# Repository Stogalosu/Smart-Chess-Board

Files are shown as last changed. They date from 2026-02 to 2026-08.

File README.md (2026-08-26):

# Smart Chess Board

## What?
A smart chess board that connects to your phone and automatically makes the moves you and your opponent make on the screen. It can even play against you! It works by moving a magnet under the board, thus also moving the pieces which will have magnets in them.

## Why?
Because I had this idea in the back if my head for a long time and I thought this was the perfect time. Also, I wanted a challenge, something new.

## How do I use it?
Well, I haven't thought it through, but my idea is to also make an Android app that connects through Bluetooth with the board so you can visualise the moves there, as well as make new ones. I also hope to allow players to make their own moves on the board using the Hall sensors that are in the board.

## Firmware
There is no firmware... yet. I've just finished assembling the board and will start working on the firmware soon. 

## Disclosure
This project has already been submitted to Blueprint a few months ago. In the meantime, I've made some small additions and adjustments that I've recorded using Lapse. These include:
- Adding pin holes on the x-axis idlers for the pulleys and then increasing their tolerances.
- Modifying X-carriage to avoid interference of belts with other moving pieces.
- Adding snap fit to every chess piece.
- Adding fillets to board edges.
- Reworking screw holes on the sides of the board.
- Strengthening the bottom of the board.
- Adjusting eject mechanism angle.
- Adjusting position of holes for Raspberry Pi.
- Adding holes in the bottom of the board for belt tensioning screws.
- Adding spaces for pin solders on the back of the PCB.
- Widening nut spaces in all pieces.
- Fixing nut holes for the motor holes; the nut was too close to the motor.
- Fixing small problems before shipping.

## Assembly
Print all pieces. Make sure to follow the color scheme of a real chess board and keep track of which piece is which, as some of the screw holes won't align if their positions are wrong. Slide together the 4 pieces that make up the bottom of the board while inserting the y-axis rods, the x-axis idlers and the x-axis guiderail. Screw in the motor holders and the motors. Cut your belt into 2 pieces. Slide them into the x-axis carriage and fit the belts on the pulleys as described in the following image. Screw in the x-axis carriage. Attach the servomotor.



Solder the pieces onto the PCB and solder them together by connecting the pins. Connect the botton pieces of the play surface with the little pins. Fit the PCBs into it, then screw in each wall piece while keeping track of its position. Connect the motor cables and the Raspberry Pi.

At the end, cover the bottom with the play surface and screw in all the screws. Done!

## Images
Build:


3D Render:


PCB that has the Raspberry Pi on it:


The other PCB, which will be used 3 times to form a grid:


Wiring diagrams for the special PCB:



Wiring diagram for tileable PCB:


## BOM table
|Name |Price/unit|Amount|Shipping|Product Cost|Notes |Link |
|---|---|---|---|---|---|---|
|X-axis guiderail |$13,37 |1 |$0,00 |$13,37 |MGN9H, 350mm |https://www.aliexpress.com/item/1005002516956172.html |
|Y-axis Steel Rod |$2,21 |2 |$1,12 |$5,54 |6mm, 350mm |https://www.aliexpress.com/item/1005007648646117.html |
|Y-axis Linear Bearing |$1,26 |2 |$0,00 |$2,52 |LM6UU |https://www.optimusdigital.ro/ro/mecanica-rulmenti/3812-rulment-liniar-lm6uu.html |
|Stepper Motor |$3,88 |2 |$0,00 |$7,76 | |https://www.optimusdigital.ro/ro/motoare-motoare-pas-cu-pas/101-driver-uln2003-motor-pas-cu-pas-de-5-v-.html|
|Servomotor |$3,20 |1 |$0,00 |$3,20 | |https://www.optimusdigital.ro/ro/motoare-servomotoare/26-micro-servomotor-sg90.html |
|Neodymium Magnet 6x3mm |$2,26 |1 |$0,00 |$2,26 | |https://www.emag.ro/magnet-neodim-disc-6mm-x-3mm-00004824/pd/DZW0Y6BBM/ |
|Neodymium Magnet 10x3mm |$6,97 |2 |$6,48 |$20,42 |100pcs |https://www.aliexpress.com/item/1005010439392352.html |
|GT2 Belt |$2,31 |1 |$1,82 |$4,13 | |https://www.robofun.ro/3d-printer-cnc/curea-gt2-la-metru-liniar.html |
|M3x6 Headless Screws |$0,08 |10 |$0,00 |$0,77 | |https://www.optimusdigital.ro/ro/mecanica-suruburi-si-piulite/5785-m3x6-mm-urub-de-fixare-cu-cap-plat.html  |
|M3x6 Screws |$0,02 |100 |$6,00 |$8,00 |Minimum quantity|https://www.tme.eu/ro/details/m3x6_d912-a2/suruburi-cu-piulita/kraftberg/ |
|M3x10 Screws |$0,03 |100 |$0,00 |$3,20 |Minimum quantity|https://www.tme.eu/ro/details/b3x10_bn3/suruburi-cu-piulita/bossard/1003771/ |
|Steel Pins 2.5x10mm |$4,60 |1 |$0,00 |$4,60 |50pcs |https://www.aliexpress.com/item/1005003326358562.html |
|Steel Pins 4x30mm |$5,04 |1 |$0,00 |$5,04 |20pcs |https://www.aliexpress.com/item/1005003326358562.html |
|GT2 Timing Pulleys 5pcs |$5,53 |1 |$2,99 |$8,52 |20T W6 B5 |https://www.aliexpress.com/item/1005001933418605.html |
|GT2 Idler Timing Pulleys 12pcs|$9,28 |2 |$2,99 |$21,55 |20T W6 B4 |https://www.aliexpress.com/item/1005007557987612.html |
|Hall Sensors |$0,41 |65 |$0,00 |$26,65 | |https://www.tme.eu/ro/details/ss30at/senzori-hall/honeywell/ |
|I2C I/O expander |$1,66 |1 |$0,00 |$1,66 | |https://www.tme.eu/ro/en/details/tca9555pwr/interfaces-others-integrated-circuits/texas-instruments/ |
|I2C Driver |$1,69 |1 |$0,00 |$1,69 | |https://www.tme.eu/ro/en/details/tbd62083afwg/drivers-integrated-circuits/toshiba/ |
|Resistor network |$0,30 |1 |$0,00 |$0,30 | |https://www.tme.eu/ro/en/details/4609x-101-103lf/resistor-networks/bourns/ |
|Bus transciever |$0,80 |1 |$0,00 |$0,80 | |https://www.tme.eu/ro/en/details/sn74hct245dwr/latches/texas-instruments/ |
|Resistors |$0,03 |5 |$0,00 |$0,13 | |https://www.tme.eu/ro/details/rc1206fr-072k7/rezistente-smd/yageo/rc1206fr-072k7l/ |
|Inductors |$0,41 |4 |$0,00 |$1,64 | |https://www.tme.eu/ro/details/b82422h1103k000/inductoare/epcos-tdk/ |
|Polarized Capacitors |$0,70 |4 |$0,00 |$2,80 | |https://www.tme.eu/ro/details/tajc107k010r/condensatoare-cu-tantal-smd/kyocera-avx/tajc107k010rnj/ |
|Capacitors |$0,17 |3 |$0,00 |$0,51 | |https://www.tme.eu/ro/details/cl31b104kbcnnnd/condensatoare-mlcc-smd/samsung/ |
|40 pin Connector Female |$0,46 |1 |$0,00 |$0,46 | |https://www.tme.eu/ro/details/zl262-40dg/pini-cu-benzi-si-soclu/connfly/ds1023-2-20s21/ |
|40 pin Connector Male |$4,51 |1 |$0,00 |$4,51 | |https://www.tme.eu/ro/details/zl2038-40/pini-cu-benzi-si-soclu/ninigi/ |
|7 pin Connector Female |$0,08 |10 |$0,00 |$0,81 |Minimum quantity|https://www.tme.eu/ro/details/zl262-7sg/pini-cu-benzi-si-soclu/connfly/ds1023-1-7s21/ |
|4 pin Connector Female |$0,08 |10 |$0,00 |$0,78 |Minimum quantity|https://www.tme.eu/ro/details/zl262-4sg/pini-cu-benzi-si-soclu/connfly/ds1023-1-4s21/ |
|3 pin Connector Male |$0,17 |1 |$0,00 |$0,17 | |https://www.tme.eu/ro/details/tsw-103-07-l-s/pini-cu-benzi-si-soclu/samtec/ |
|PCBs |$29,40 |1 |$22,59  |$51,99 | | |
|Total Cost | | |$43,99  |$205,78 | | |

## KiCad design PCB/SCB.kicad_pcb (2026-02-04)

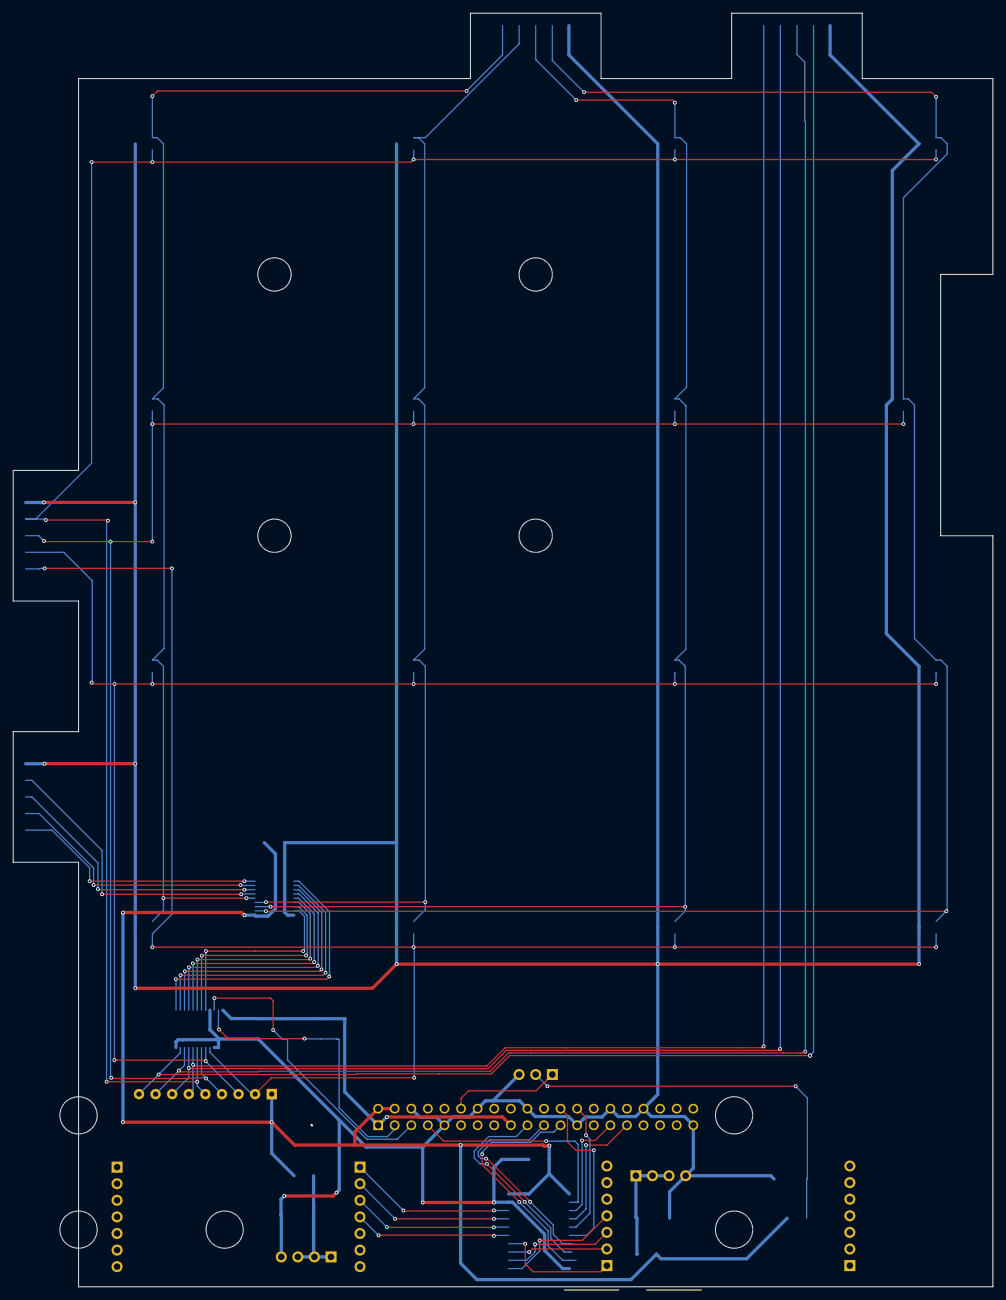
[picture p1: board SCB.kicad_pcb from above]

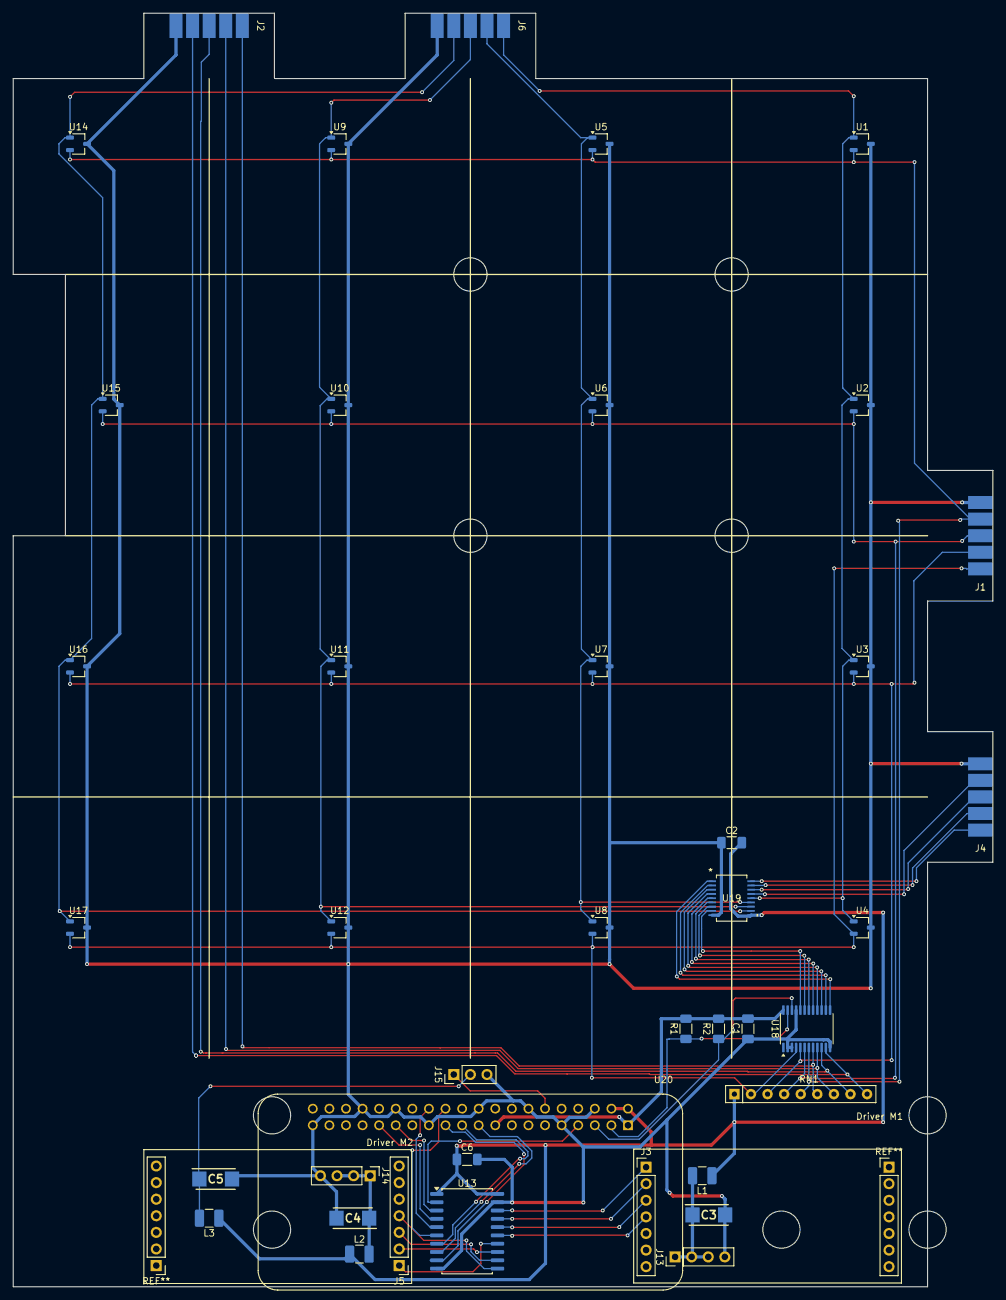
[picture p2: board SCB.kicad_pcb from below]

Board: 2 copper layers, 150.0 x 195.0 mm, 41 parts (40 on the bottom side), 49 nets.

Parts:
C1: C1; C_1206_3216Metric_Pad1.33x1.80mm_HandSolder
C2, C6: C; C_1206_3216Metric_Pad1.33x1.80mm_HandSolder
C3, C4, C5: C_Polarized; CAPPM6032X280N
J1, J2, J4, J6: Conn_01x05; Connector_5_Pads
J3, J5: Conn_01x07; PinHeader_1x07_P2.54mm_Vertical
J13, J14: Conn_01x04; PinHeader_1x04_P2.54mm_Vertical
J15: Conn_01x03; PinHeader_1x03_P2.54mm_Vertical
L1, L2, L3: L; L_1210_3225Metric_Pad1.42x2.65mm_HandSolder
R1, R2: R; R_1206_3216Metric_Pad1.30x1.75mm_HandSolder
RN1: R_Network08; R_Array_SIP9
U1, U2, U3, U4, U5, U6, U7, U8, U9, U10, U11, U12, U14, U15, U16, U17: TSOT-23
U13: SN74HCT245DWR; SOIC-20W_7.5x12.8mm_P1.27mm
U18: TCA9555PWR; TSSOP-24_4.4x7.8mm_P0.65mm
U19: TBD62083AFWG; SSOP18-P-225-0p65_TOS
U20: RASPBERRY_PI_ZERO_2_W; MODULE_RASPBERRY_PI_ZERO_2_W

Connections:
+3V3: C1.1, R1.2, R2.2, U18.24 (VCC), U20.1 (3V3_1), U20.17 (3V3_17)
+5V: C2.2, C6.1, L1.1, L2.1, L3.1, RN1.1 (common), U13.1 (A->B), U13.20 (VCC), U19.10 (COMMON), U20.2 (5V_2), U20.4 (5V_4)
/Matrice 4x4 cu controller/CA_IN: J4.1, U19.18 (O1)
/Matrice 4x4 cu controller/CB_IN: J4.2, U19.17 (O2)
/Matrice 4x4 cu controller/CC_IN: J4.3, U19.16 (O3)
/Matrice 4x4 cu controller/CD_IN: J4.4, U19.15 (O4)
/Matrice 4x4 cu controller/CE_IN: J6.1, U1.1 (VCC), U2.1 (VCC), U3.1 (VCC), U4.1 (VCC), U19.14 (O5)
/Matrice 4x4 cu controller/CF_IN: J6.2, U5.1 (VCC), U6.1 (VCC), U7.1 (VCC), U8.1 (VCC), U19.13 (O6)
/Matrice 4x4 cu controller/CG_IN: J6.3, U9.1 (VCC), U10.1 (VCC), U11.1 (VCC), U12.1 (VCC), U19.12 (O7)
/Matrice 4x4 cu controller/CH_IN: J6.4, U14.1 (VCC), U15.1 (VCC), U16.1 (VCC), U17.1 (VCC), U19.11 (O8)
/Matrice 4x4 cu controller/L1_IN: J1.1, RN1.2 (R1), U4.2 (OUT), U8.2 (OUT), U12.2 (OUT), U17.2 (OUT), U18.4 (P00)
/Matrice 4x4 cu controller/L2_IN: J1.2, RN1.3 (R2), U3.2 (OUT), U7.2 (OUT), U11.2 (OUT), U16.2 (OUT), U18.5 (P01)
/Matrice 4x4 cu controller/L3_IN: J1.3, RN1.4 (R3), U2.2 (OUT), U6.2 (OUT), U10.2 (OUT), U15.2 (OUT), U18.6 (P02)
/Matrice 4x4 cu controller/L4_IN: J1.4, RN1.5 (R4), U1.2 (OUT), U5.2 (OUT), U9.2 (OUT), U14.2 (OUT), U18.7 (P03)
/Matrice 4x4 cu controller/L5_OUT: J2.1, RN1.6 (R5), U18.8 (P04)
/Matrice 4x4 cu controller/L6_OUT: J2.2, RN1.7 (R6), U18.9 (P05)
/Matrice 4x4 cu controller/L7_OUT: J2.3, RN1.8 (R7), U18.10 (P06)
/Matrice 4x4 cu controller/L8_OUT: J2.4, RN1.9 (R8), U18.11 (P07)
/Raspberry/IO_4: U13.2 (A0), U20.7 (GPIO4/GPIO_GCLK)
/Raspberry/IO_5: U13.3 (A1), U20.29 (GPIO5)
/Raspberry/IO_6: U13.4 (A2), U20.31 (GPIO6)
/Raspberry/IO_7: U13.5 (A3), U20.26 (GPIO7/SPI_~CE1)
/Raspberry/IO_8: U13.6 (A4), U20.24 (GPIO8/SPI_~CE0)
/Raspberry/IO_9: U13.7 (A5), U20.21 (GPIO9/SPI_MISO)
/Raspberry/IO_10: U13.8 (A6), U20.19 (GPIO10/SPI_MOSI)
/Raspberry/IO_11: U13.9 (A7), U20.23 (GPIO11/SPI_SCLK)
/Raspberry/M1_1: J3.1, U13.18 (B0)
/Raspberry/M1_2: J3.2, U13.17 (B1)
/Raspberry/M1_3: J3.3, U13.16 (B2)
/Raspberry/M1_4: J3.4, U13.15 (B3)
/Raspberry/M2_1: J5.1, U13.14 (B4)
/Raspberry/M2_2: J5.2, U13.13 (B5)
/Raspberry/M2_3: J5.3, U13.12 (B6)
/Raspberry/M2_4: J5.4, U13.11 (B7)
/Raspberry/MZ: J15.1, U20.12 (GPIO18/GPIO_GEN1)
GND: C1.2, C2.1, C3.2, C4.2, C5.2, C6.2, J1.5, J2.5, J4.5, J6.5, J13.4, J14.4, J15.3, U1.3 (GND), U2.3 (GND), U3.3 (GND), U4.3 (GND), U5.3 (GND), U6.3 (GND), U7.3 (GND), U8.3 (GND), U9.3 (GND), U10.3 (GND), U11.3 (GND), U12.3 (GND), U13.10 (GND), U13.19 (CE), U14.3 (GND), U15.3 (GND), U16.3 (GND), U17.3 (GND), U18.2 (A1), U18.3 (A2), U18.12 (GND), U18.21 (A0), U19.9 (GND), U20.6 (GND_6), U20.9 (GND_9), U20.14 (GND_14), U20.20 (GND_20), U20.25 (GND_25), U20.30 (GND_30), U20.34 (GND_34), U20.39 (GND_39)
unnamed: C3.1, J13.1, J13.2, J13.3, L1.2
unnamed: C4.1, J14.1, J14.2, J14.3, L2.2
unnamed: C5.1, J15.2, L3.2
unnamed: U18.13 (P10), U19.1 (I1)
unnamed: U18.14 (P11), U19.2 (I2)
unnamed: U18.15 (P12), U19.3 (I3)
unnamed: U18.16 (P13), U19.4 (I4)
unnamed: U18.17 (P14), U19.5 (I5)
unnamed: U18.18 (P15), U19.6 (I6)
unnamed: U18.19 (P16), U19.7 (I7)
unnamed: U18.20 (P17), U19.8 (I8)
SCL: R2.1, U18.22 (SCL), U20.5 (GPIO3/SCL)
SDA: R1.1, U18.23 (SDA), U20.3 (GPIO2/SDA1)

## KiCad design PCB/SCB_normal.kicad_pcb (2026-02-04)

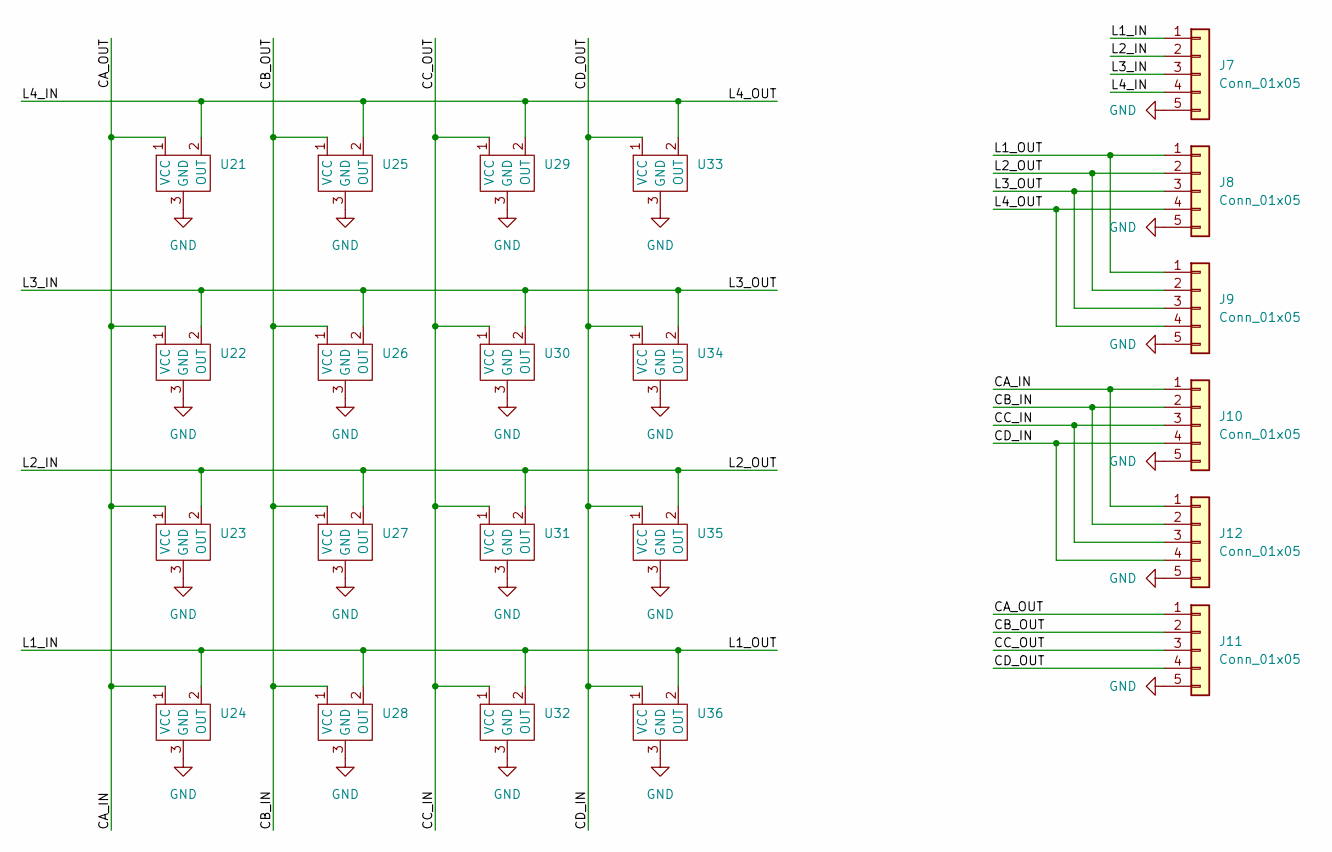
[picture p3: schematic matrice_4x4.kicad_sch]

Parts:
J7, J8, J9, J10, J11, J12: Conn_01x05; Connector_5_Pads
U21, U22, U23, U24, U25, U26, U27, U28, U29, U30, U31, U32, U33, U34, U35, U36: TSOT-23

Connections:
/Matrice 4x4/CA_IN: J10.1, J11.1, J12.1, U21.1 (VCC), U22.1 (VCC), U23.1 (VCC), U24.1 (VCC)
/Matrice 4x4/CB_IN: J10.2, J11.2, J12.2, U25.1 (VCC), U26.1 (VCC), U27.1 (VCC), U28.1 (VCC)
/Matrice 4x4/CC_IN: J10.3, J11.3, J12.3, U29.1 (VCC), U30.1 (VCC), U31.1 (VCC), U32.1 (VCC)
/Matrice 4x4/CD_IN: J10.4, J11.4, J12.4, U33.1 (VCC), U34.1 (VCC), U35.1 (VCC), U36.1 (VCC)
/Matrice 4x4/L1_IN: J7.1, J8.1, J9.1, U24.2 (OUT), U28.2 (OUT), U32.2 (OUT), U36.2 (OUT)
/Matrice 4x4/L2_IN: J7.2, J8.2, J9.2, U23.2 (OUT), U27.2 (OUT), U31.2 (OUT), U35.2 (OUT)
/Matrice 4x4/L3_IN: J7.3, J8.3, J9.3, U22.2 (OUT), U26.2 (OUT), U30.2 (OUT), U34.2 (OUT)
/Matrice 4x4/L4_IN: J7.4, J8.4, J9.4, U21.2 (OUT), U25.2 (OUT), U29.2 (OUT), U33.2 (OUT)
GND: J7.5, J8.5, J9.5, J10.5, J11.5, J12.5, U21.3 (GND), U22.3 (GND), U23.3 (GND), U24.3 (GND), U25.3 (GND), U26.3 (GND), U27.3 (GND), U28.3 (GND), U29.3 (GND), U30.3 (GND), U31.3 (GND), U32.3 (GND), U33.3 (GND), U34.3 (GND), U35.3 (GND), U36.3 (GND)

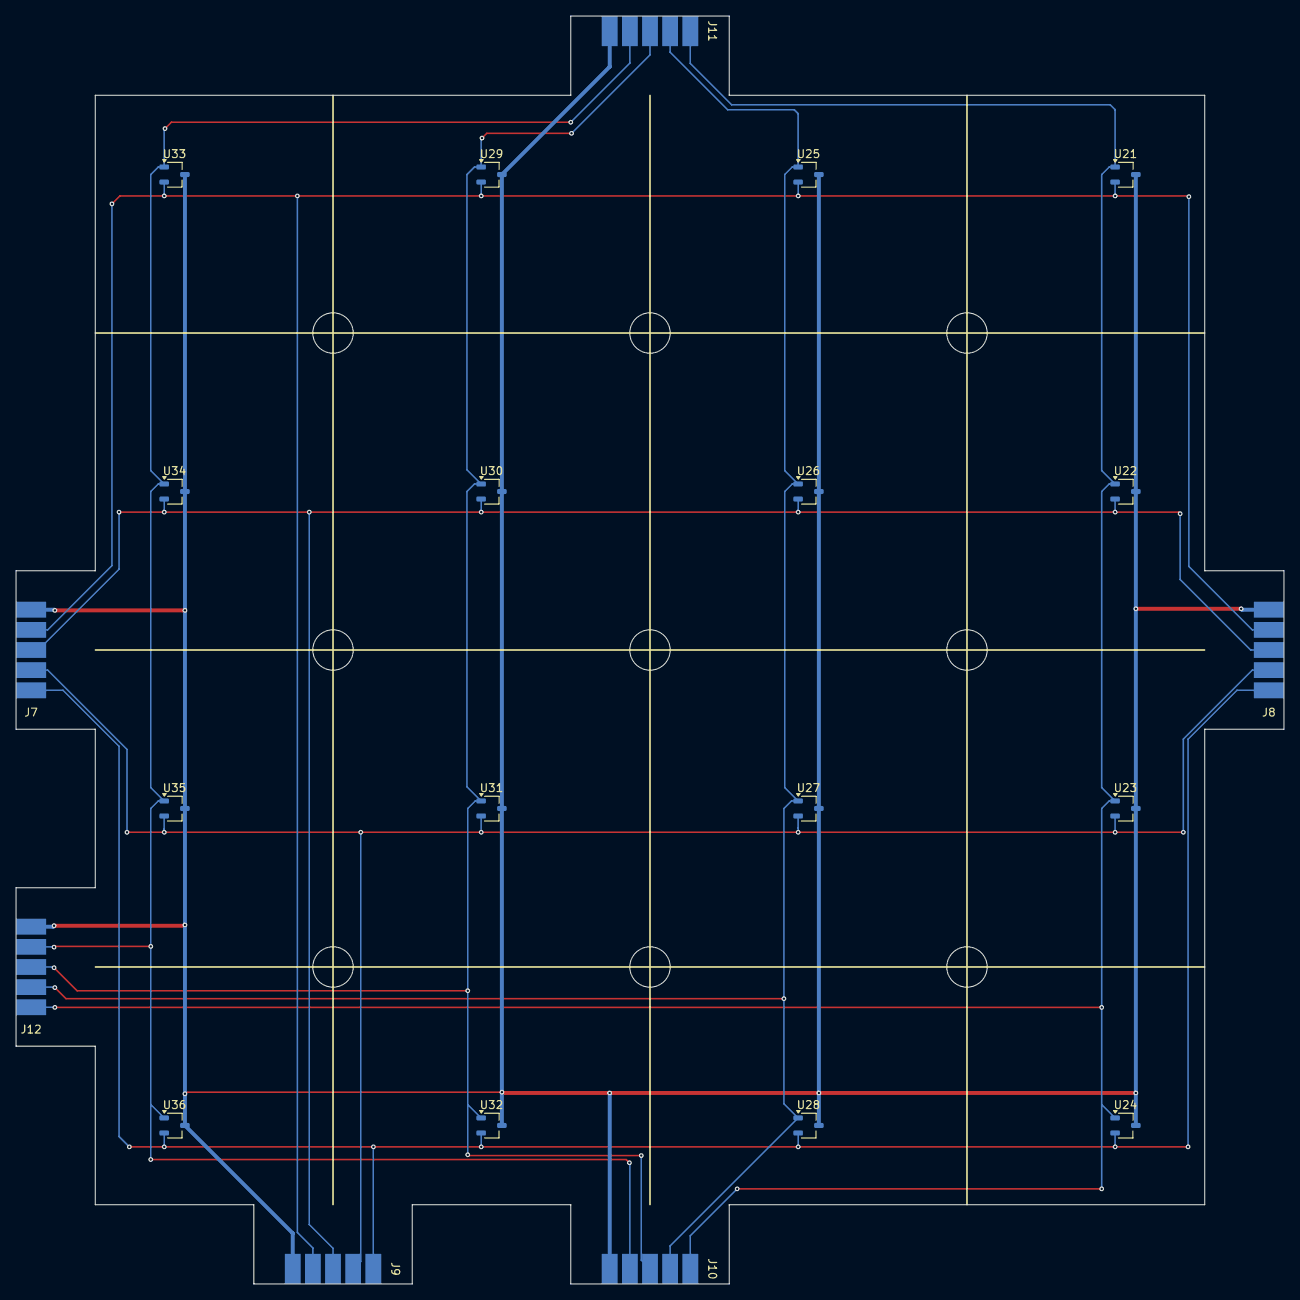
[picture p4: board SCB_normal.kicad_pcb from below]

Board: 2 copper layers, 160.0 x 160.0 mm, 22 parts (22 on the bottom side), 9 nets.

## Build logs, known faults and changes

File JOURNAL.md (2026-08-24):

<!--
  This journal is auto generated by Hack Club Blueprint.
-->
# for Blueprint

# 6/11/2025 - Made the first version of the board design  

_Time spent: 2.7h_  

4.11.25
I spent about 45 minutes researching possible parts for the project, including stepper motors, electromagnets and main boards. I was initially thinking about using an Arduino board, but I realized that the GUI app that I want to build is very complicated to write in C, so I switched to a Raspberry Pi.

5.11.25
I designed the top of the board in Fusion 360. It was to big to 3d print (on my own printer) in one piece, so I had to break it up into 4 smaller ones. I made a cross-shaped beam with holes to hold them together. That was also too big, so it had to be spit up as well. I chose to connect it all in the middle, but I have some concerns with it being too thin. I hope it will hold up.

Here is the bottom side of the board, without the beam. The top side looks like any other chess board.


This is the beam.


# 10/11/2025 - Tweaked board and created XY-joint  

_Time spent: 4.0h_  

6.11.2025
Instead of pins coming out the beam to hold the board together, I decided to use some stainless steel pins that connect the beam with the pieces and made the necessary adjustments. This took about 30 minutes.

9.11.2025
Added screw holes on the side of the board for attachment to the case. I used M3 screws. This didn't take a lot of time, but I also did some research on the core xy cartesian system, which I plan on using (about 1 hour in total)

10.11.2025
Did some more research on a possible electromagnet, steel rods for the y-axis and linear guiderail for the x-axis and made a xy-joint: a piece which contains a linear bearing that runs along the y-axis and attaches to the guiderail of the x-axis.
I decided to get rid of the bead that holds the board together and just use those steel pins to join the pieces directly, but haven't made the changes.

Here is the modified board:


and the xy-joint (it's still and early prototype, I have to split it in two and add screw holes):


# 14/11/2025 - Worked on Core XY System  

_Time spent: 4.0h_  

10.11.2025
I added screw holes to the xy joint. I then had to move them on the other side, because on the top of the joint I will have to mount the idler pulleys. I also gave up on the hexagonal shape, because it was too hard to 3d print.

14.11.2025
I started work on the part that actually moves the chess pieces around. I designed the guiderail carriage  and thought of an idea of how to move a permanent magnet up and down using a servomotor. I started the sketch for the mechanism.

Here is the xy joint seen from below:


Here is the sketch for the carriage. I am thinking of a mechanism that uses a disc with a pin to pull a rod that has the magnet at the end up and down.


And this is the core XY system so far:


# 15/11/2025 - Designed the magnet mechanism  

_Time spent: 2.5h_  

15.11.2025
I finished the design of the mechanism I started yesterday. As I said, I went for a piece that holds the magnet and goes up and down, guided by the holes in a bigger piece. It is moved by a disc with a pin.
I 3d printed what I thought was a working version, but, apparently, some tolerances and dimensions had been messed up when I made some edits. I fixed them and I'm going to print the new version tomorrow.

Here is the big piece with the magnet-holding one in it:


An this is the wheel with the pin. You can see how it interacts with the one with the magnet.


# 24/11/2025 - Worked on the carriage  

_Time spent: 3.0h_  

16.11.2025
I made some adjustments and printed a version that, with a bit of sanding, was great. I had some concerns about the pin breaking, but that didn't happen, now I have to see if a magnet of the chosen size will be strong enough.

During the week, I added screw holes to mount the mechanism to the guiderail carriage. I had some trouble because the disc was in the way of the screws and I had to use headless screws for that part. I also struggled with the dimensions of the servomotor and didn't make much progress because of it.

24.11.2025
I found a 3d model of the servomotor that allowed me to design the mounting. The problem is that it partly obstructs the hole where the wheel is inserted, So I had to make a bit of space and shrink the wheel. I hope it'll fit.

Here is the mounting without the motor:


And here it is with it:


# 4/12/2025 - Added pulleys and belt attachment holes  

_Time spent: 2.9h_  

29.11.2025
I made the first sketches for the core xy system: I placed the pulleys.

30.11.2025
I modeled the pulleys according the the ones I decided on using. I'm using the same ones usually found in 3d printers. I also searched for steel pins to fixate the pulleys and modeled holes for the belts to attach to the carriage. I was inspired by my Prusa 3d printer that has something similar.

3.12.2025
I positioned the pulleys on two levels to allow the two belts to work independently.

Here you can see the holes for the belt:


And here is the whole system, with the pulleys spread on two levels:


# 21/12/2025 - Created mount for stepper motors  

_Time spent: 4.1h_  

Over the past week I've had some challenges with the motors. I realized they were too big to fit in the vertical space that I had arbitrarily chosen. This was not all that bad, as I could just make the whole board taller, but they also didn't fit sideways: the carriage would have hit them when going to the corner and the belt would have had some weird angles. I then thought of methods to make them fit. The idea I came up with was to make the x-axis longer, thus creating space for lowering the pulleys. In my head, this would allow me to fit a slimmer motor upside down, over the pulleys. I did not have the space and these motors were much more powerful and required move power, which I didn't really have any idea how to supply.

I began to worry that I might not be able to work this out, but, after scrapping the slim motor idea, I realized that rotating my current motor would solve the carriage problem. I would just have to accept the board is now about 6 cm tall. I thought this was my only option, so I went for it.

I created the mounts for the motors, as well as what I hope to be a belt tensioning system that uses screws to move the mount and the motor.

Here is the left mount:


And here is the right one:


# 26/12/2025 - Redesigned board and created ejecting mechanism  

_Time spent: 4.2h_  

Since the last entry, I've tweaked the board design. I've removed the connecting beam and the 4 pieces now directly connect using steel pins. I've also extended the lateral walls and added screw holes. After that, I created the mechanism for ejecting pieces off the board, after they are taken by the other player. I chose a special square and I added a hinge to allow it to rotate about 20 degrees in order for the chess piece to slide off the table. I initially had two ideas that are hard to describe, but I ended up adding some prisms to both the special square and the magnet carriage that allow the carriage to rotate the square.

Here is the special square seen from underneath. You can see the prism:


Here is the ramp I added for the sliding piece. You can also see the prism added to the carriage:


And here is the whole board:


# 17/1/2026 - Created schematic for PCB  

_Time spent: 5.7h_  

27.12-29.12.2025
Beside moving the pieces, I want the board to also detect where the pieces are on the table, so I can also make my moves. For this, I am making a PCB that will go directly under the pieces. It will have hall sensors for every piece, thus being able to detect their presence.
So I started to design the schematic. My dad helped my throughout the process. I decided to use a Raspberry Pi Zero for the board, because the other ones were too big. Because the board requires a 8x8 matrix, we used a I2C expander to reduce the number of pins needed. We also added another chip that provides more current for the sensors. I also thought of integrating connectors for the stepper motors and servomotor that connect to the Raspberry Pi. For connecting the stepper motors, we had to use an 8-bit buffer for logic level change. (conversion from 3V supplied by the pi to 5V required by the motors). 

Because the board is split into 4, the PCB had to be spit as well. Because of this, at the end, we put some thought into the placement of connectors that connect the 8x8 matrix to the Pi. We positioned them so that 3 of the 4 PCBs are identical, to save on cost. The 4th one has all the chips and motor connectors on it, as well as the cutout for the piece eject system.

Here is the schematic, broken into 3 pages:

This is for the 3 identical PCBs


This is the special one


And this page is dedicated to the Pi and the connectors for the motors
  

# 18/1/2026 - Started PCB  

_Time spent: 2.0h_  

29.12.2025
I assigned all of the footprints to all of the parts. Some of them were harder to find. I also searched and settled on some pulleys. I updated the BOM to include them and started designing the PCB. I made a simple box and arranged the sensors according to the dimensions of the board.

Here it is:


# 26/1/2026 - Finished the PCB layout  

_Time spent: 4.7h_  

17.01-18.01.2025
I arranged all of the components on the PCB and settled on a design that has some extensions that connect with neighboring PCBs. On the special PCB, I crammed the stepper motor drivers and the Raspberry Pi connectors. I had to overlap them to make them fit, and I will buy a longer header for the Pi.
Before doing the routing, I'm going to continue designing in Fusion.

Here is the normal PCB:


And here is the special one:


# 28/1/2026 - Starting to wrap up  

_Time spent: 7.5h_  

Over the past week, I've been busy fixing little details and putting the project together. I've made spaces for the components on the PCB, I've searched and imported 3d models for the connectors, Raspberry Pi and drivers. I've also painstakingly extruded all the holes for screws and nuts that will keep the whole thing together and rearranged the pins that connect the 4 quarters of the board.

This is how it looks now:


# 30/1/2026 - Adding the finishing touches  

_Time spent: 5.0h_  

29.01.2026
I added the last touches to finish the project: added screw holes in the PCB, created pins that connect the two slices of the board. The PCB goes in between them. I also created a support and a guiding piece for the servomotor cable and added holes for the pi's ports. At the end, I routed the PCB, updated the BOM and gathered all the files for submitting the project.

Here's the finished board:


and the PCBs:



# 4/2/2026 - Fixed PCB holes  

_Time spent: 0.3h_  

04.02.2026
I realized that the hole I had made in the PCB were off by almost a millimeter, so I fixed them. I also remembered that I forgot to add holes for the pins connecting the two plastic pieces of the board "sandwich".

You can see the new holes around the middle of the PCB. The tileable one has more holes, because they always have to be towards the center of the board.



# for Horizons

# 25/2/2026 - Adding pin holes to x-axis idlers

_Time spent: 0.88h_

I added holes for the pins that the pulleys go onto, as the model did not include them previously.

[Lapse recording](https://lapse.hackclub.com/timelapse/YqsuZjYVIbya)

# 10/3/2026 - More fixing and editing pieces

_Time spent: 0.25h_

I revisited the pin holes and added a small brim to prevent excessive friction between x-axis idler and pulleys. I also started editing the actual chess pieces by resizing the pawn and its magnet hole.

[Lapse recording](https://lapse.hackclub.com/timelapse/71xHFnRw1OqV)

# 11/3/2026 - Test printing and more piece editing

_Time spent: 1.06h_

Printed some cut pieces of the board to test if tolerances are right. I continued editing the pawn piece by cutting it in two pieces and adding a snap fit to allow the magnet to be inserted after print. Also, I edited X-carrige to avoid interference of belts with other moving pieces.

[Lapse recording](https://lapse.hackclub.com/timelapse/D2Eyl7nXQGMD)

# 13/3/2026 - Editing chess pieces

_Time spent: 1.68h_

I added remaining pin holes while increasing tolerances. Then, I increased the X-carriage belt tolerances and I printed a X-axis idler as well as a X-carriage to test them. I continued editing the other chess pieces in the same way as the pawn.

[Lapse recording](https://lapse.hackclub.com/timelapse/JTLcyxXzvGlR)

# 14/3/2026 - Screw holes and snap fits

_Time spent: 2.08h_

When slicing the bottom parts of the board, I realized that the screw holes were not that pretty, so I reworked them. I finished editing the chess pieces and now have a complete set and each piece can have a magnet inserted into it. Also, I added fillets to the sides of the board to make it prettier.

[Lapse recording](https://lapse.hackclub.com/timelapse/GV2tJu4BBnWR)

# 15/3/2026 - Puzzles and holes

_Time spent: 0.76h_

I (hopefully) strengthened the bottom of the board by adding puzzle-like connectors. I adjusted Raspberry Pi and pin holes according to connector length and adjusted eject mechanism angle after realizing that it would collide with the belts.

[Lapse recording](https://lapse.hackclub.com/timelapse/B2BEkGx1v8uj)

# 16/3/2026 - Belt tensioning

_Time spent: 0.96h_

I worked on the belt tensioning mechanism by making a screw hole in the motor holder and an elongated one on the bottom of the board. This way, the motor can be pulled to stretch the belt and then fixed in place by tightening the screws. I also printed the cable holder for the stepper motor to test it and finally began printing the board by printing the first bottom quarter.

In the second session, I added spaces for pin solders on the back of the PCB and widened spaces for nuts in all pieces.

[Lapse recording 1](https://lapse.hackclub.com/timelapse/-cZruy2iMTlf)
[Lapse recording 2](https://lapse.hackclub.com/timelapse/mS02Os0n7fhu)

# 17/3/2026 - Fixing motor nuts

_Time spent: 0.28h_

I fixed nut holes for the motor holes: the nut was too close to the motor and wouldn't have entered the hole completely.

[Lapse recording](https://lapse.hackclub.com/timelapse/IEAsvMDNfgVc)

# 20/5/2026 - Final check before print

_Time spent: 0.8h_

I checked everything before printing and repaired little mistakes. I again moved the Raspberry Pi pin holes, which, apparently, were not in the right place, I added fillets to the eject mechanism, I added tolerances for the PCB. Then, after everything was right, I exported all of the pieces I had to print.

[Lapse recording](https://lapse.hackclub.com/timelapse/4Uwjsaszz5XT)

# 23/5/2026 - Chamfer and slicing

_Time spent: 0.68h_

I added chamfers to the edges of the board to hopefully make them fit together easier and sliced all top quarters using multiple colors.

[Lapse recording](https://lapse.hackclub.com/timelapse/xWTb6wggGUwi)

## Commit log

2026-01-29 Enhance README with project details and BOM
    Expanded README to include detailed project description, usage instructions, images, and BOM table.
2026-01-30 Uploaded all project files
    [BOM.csv, SCB.kicad_pcb, SCB.kicad_sch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]
2026-01-30 Updated prices in BOM
    [BOM.csv]
2026-02-04 Fixed holes in the PCBs
    [SCB.kicad_pcb, SCB_normal.kicad_pcb]
2026-07-13 Updated CAD with the latest modifications
2026-07-18 Update README with project adjustments and assembly steps
    Added detailed adjustments and assembly instructions for the project.
